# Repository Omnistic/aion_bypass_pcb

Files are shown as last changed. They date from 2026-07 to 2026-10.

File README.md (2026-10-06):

# PCB Design for Hardware Control of Confocal.nl AION in Bypass Mode
## Important Notes ⚠️
- **Current progress**: the board has been designed, printed, assembled, and tested on its own. The controller has also been tested on our microscope successfully. Using the `SELECT` line, one can either use the AION (Confocal.nl) or a FRAP/TIRF module with the AION in bypass mode.
- Floating (digital) inputs should be avoided in a channel that is actively used. I had the case when testing the board, if I only wired one input, the other floating (not wired) input could be `HIGH`.
- When testing the board, the capacitor value changes depending on how many have been soldered to the board already. If a single capacitor is soldered to the board, a multi-meter should still read 100nF. When two capacitors are soldered to the board, and one measures the value of one capacitor, it indicates 200nF. That is because the capacitors are effectively in parallel and their value adds up. With all four capacitors soldered to the board, they should all read 400nF.
## Problem
The AION microscope is controlled by Confocal.nl's own controller. The Confocal.nl controller can also be controlled by the Inscoper Device Controller. The Inscoper Device Controller can control other devices as well. For this reason, the AION can be set into an _optical bypass mode_, which allows accessing the cameras through the AION without making use of the ReScan, to instead perform other kinds of microscopy. However, the cameras and the laser lines (analog and digital) are normally wired to the Confocal.nl controller. This limits the way in which the cameras and the laser lines can be controlled at the level of the Inscoper Device Controller for use in other applications.
## Solution
For two controllers to send signals to the same device, multiplexing is necessary. In the case of the camera trigger (digital) signal, it is not possible to simply use a T-connector because if one controller is high and the other is low a large short-circuit current would flow directly between the two controllers' outputs as they fight each other, potentially damaging the controllers, while the shared node would sit at an undefined voltage that the device could not reliably interpret as high or low.
## Requirements
**⚠️ Those are for my particular case, please check the documentation of your devices accordingly.**
### Devices To Multiplex
#### Oxxius L6Cc With 4 Laser Lines
- 4 digital lines
- 4 analog lines
- Voltage Range (analog and digital): 0-5V
- Input Impedance (analog and digital): 500Ω
#### 2x Kinetix (10Mpix Version)
- 2 digital lines (Trigger In) / 1 per camera
- Voltage Range: 0-5V
- Input Impedance: Unknown
  - For reference, a similar ORCA-Fusion BT has an impedance of 10kΩ
### Selected ICs
#### Digital Multiplexing
`SN74HC157N` is a 4 x 2:1 digital multiplexer, with a single `SELECT` bit. Two will be used for a total of 8 (2:1) digital channels. Although only 6 are required.
#### Analog Multiplexing
`CD74HC4053E` is 3 x 2:1 analog multiplexer, with three `SELECT` bits (1 per channel). Two will be used for a total of 6 (2:1) analog channels. Although only 4 are required.
### PCB Design Rationale
Assuming up to two lasers are operated simultaneously, the current drawn from 2 digital and 2 analog lines is 40mA. On top of that, the two cameras only contribute 1mA (assuming 10kΩ). Multiplying by a safety factor of 1.2 that is about 50mA. The power will be supplied to the board via the Inscoper Device Controller directly.

All the `SELECT` bits are common and a single `SELECT` signal is also taken from the Inscoper Device Controller. This signal effectively switches between AION control and Inscoper control (for the cameras and lasers).

The `SELECT` line is pulled down by a 10kΩ resistor, defaulting to LOW, which corresponds to AION (for my use case).

Only the `SELECT` crosses the PCB with minimal length in the back face to keep continuous ground zone.

100nF capacitors are used on each IC for decoupling.

Vertical through-hole SMA connectors will be soldered to the PCB. The PCB will be mounted in a case and a front panel will have SMA (inside facing) to SMB (outside facing) connectors. Minimum distance between SMA connectors optimized for accessible mounting.

## Overview
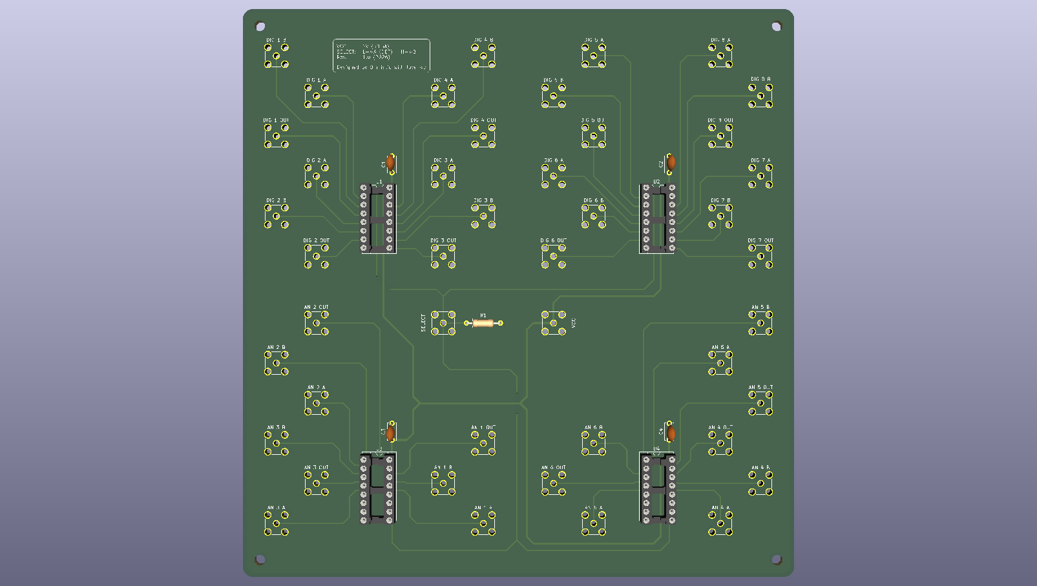
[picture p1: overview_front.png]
PCB Front View

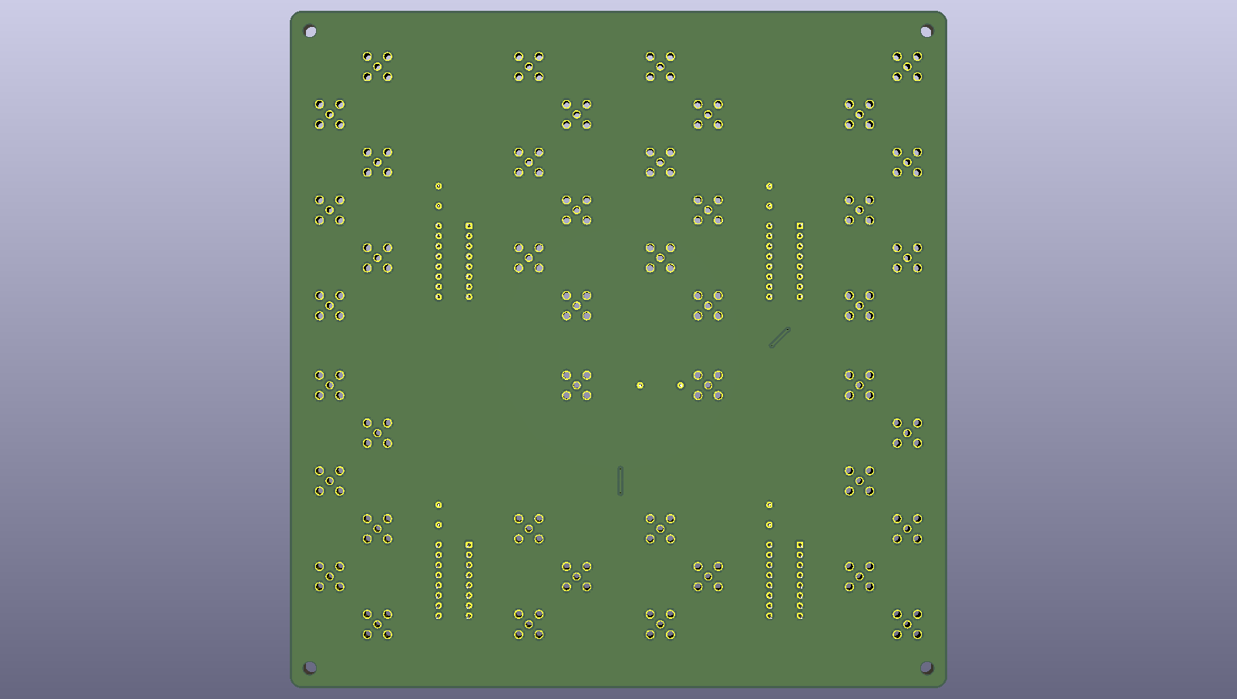
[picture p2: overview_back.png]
PCB Back View


## Realization
- Printed by JLCPCB for about 32USD (5xPCBs = 18USD + shipping = 14USD)
- Soldered manually
- We have a local electronics workshop and I'm not sure if the price are truly accurate to the market but here is a small cost breakdown:
  - **32x SMA connectors = 256USD**
  - 4x 16-pin sockets = 1USD
  - 2x SN74HC157N = 2.2USD (bought from DigiKey)
  - 2x CD74HC4053E = 1.3USD (bought from DigiKey)
  - 4x 100nF = 0.25USD
  - 1x 10kΩ = 0.05USD

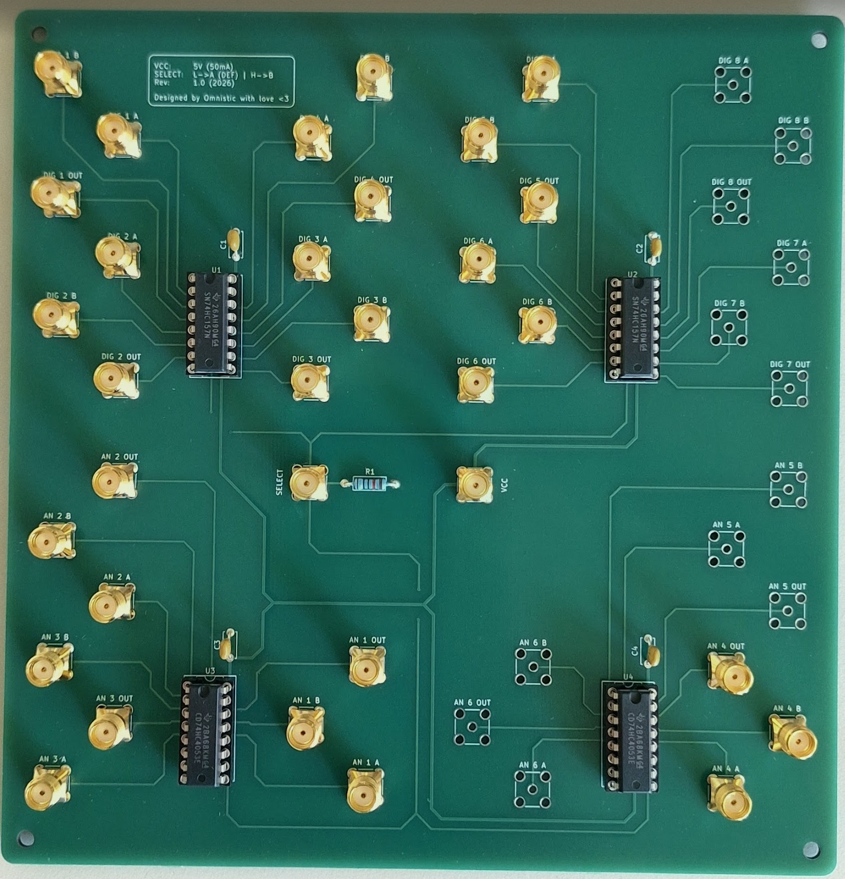
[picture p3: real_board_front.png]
PCB Real Front View


## Enclosure
- 1x Enclosure [1401E (Hammond)](https://www.hammfg.com/electronics/small-case/general-purpose/1401) = 110USD
- 32x SMA-Bulkhead cable [794-2885 (RS PRO)](https://uk.rs-online.com/web/p/coaxial-cable/7942885?gb=a) = 640USD

Note: I originally ordered SMA-Bulkhead cables that were thicker (not intentionally) but they sent only a few and the others were on back order. I cancelled the order and got those above that are thinner. The reason I say this is because it is easier to assemble with the thin cables imo. And also, I am sorry for the poor cable management... The enclosure foot print is perhaps a tiny bit too small but it works.

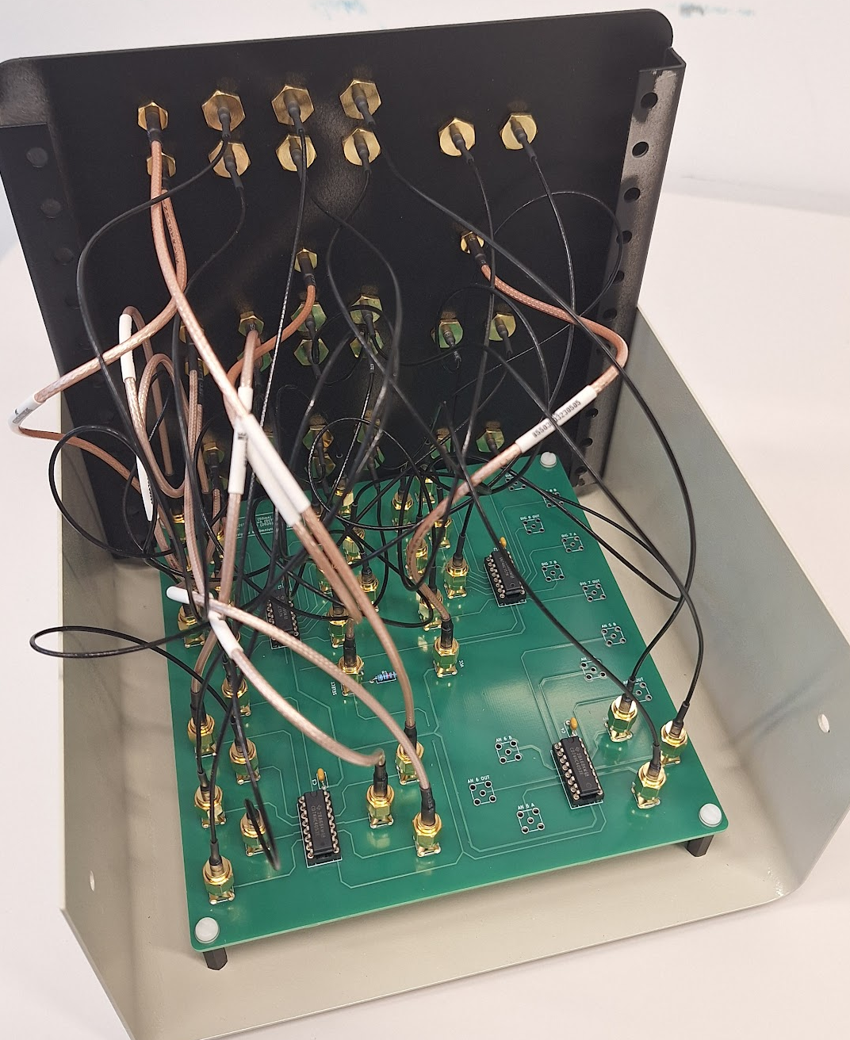
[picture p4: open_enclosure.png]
Open Enclosure

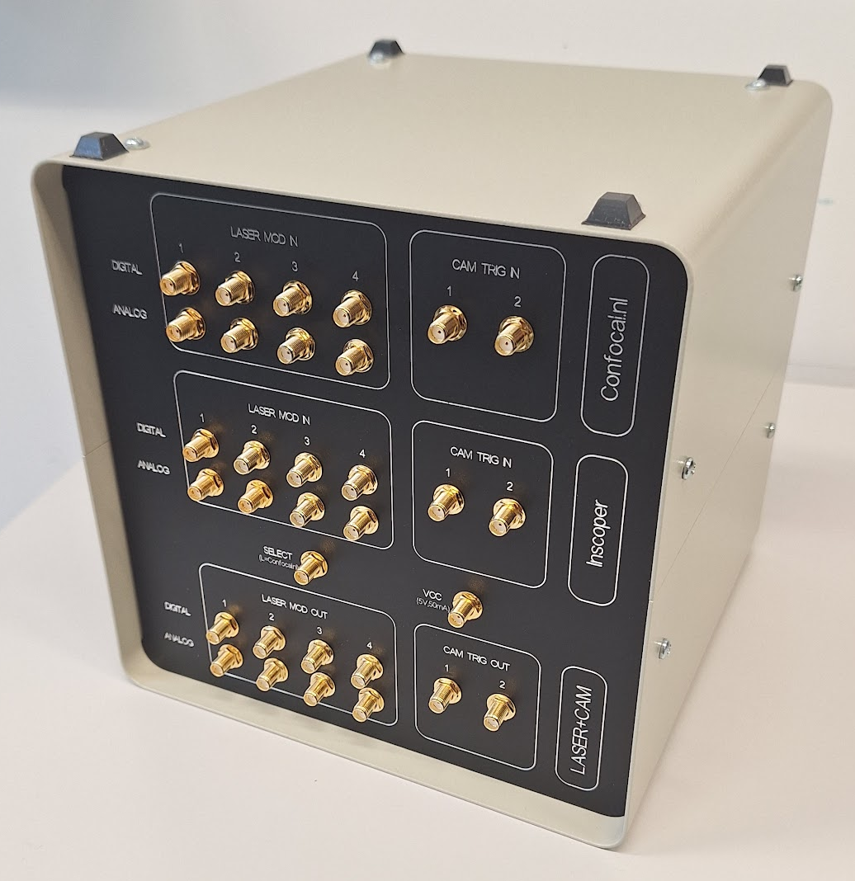
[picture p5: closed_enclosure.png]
Closed Enclosure


## Acknowledgements
We thank Alfonso Fontao Blanco from the [Microelectronics Design Center (ETHZ)](https://dz.ethz.ch/) for kindly reviewing the design and suggesting minor improvements (more distance between SMA connectors, mounting holes, shorter `SELECT` line on the back face).

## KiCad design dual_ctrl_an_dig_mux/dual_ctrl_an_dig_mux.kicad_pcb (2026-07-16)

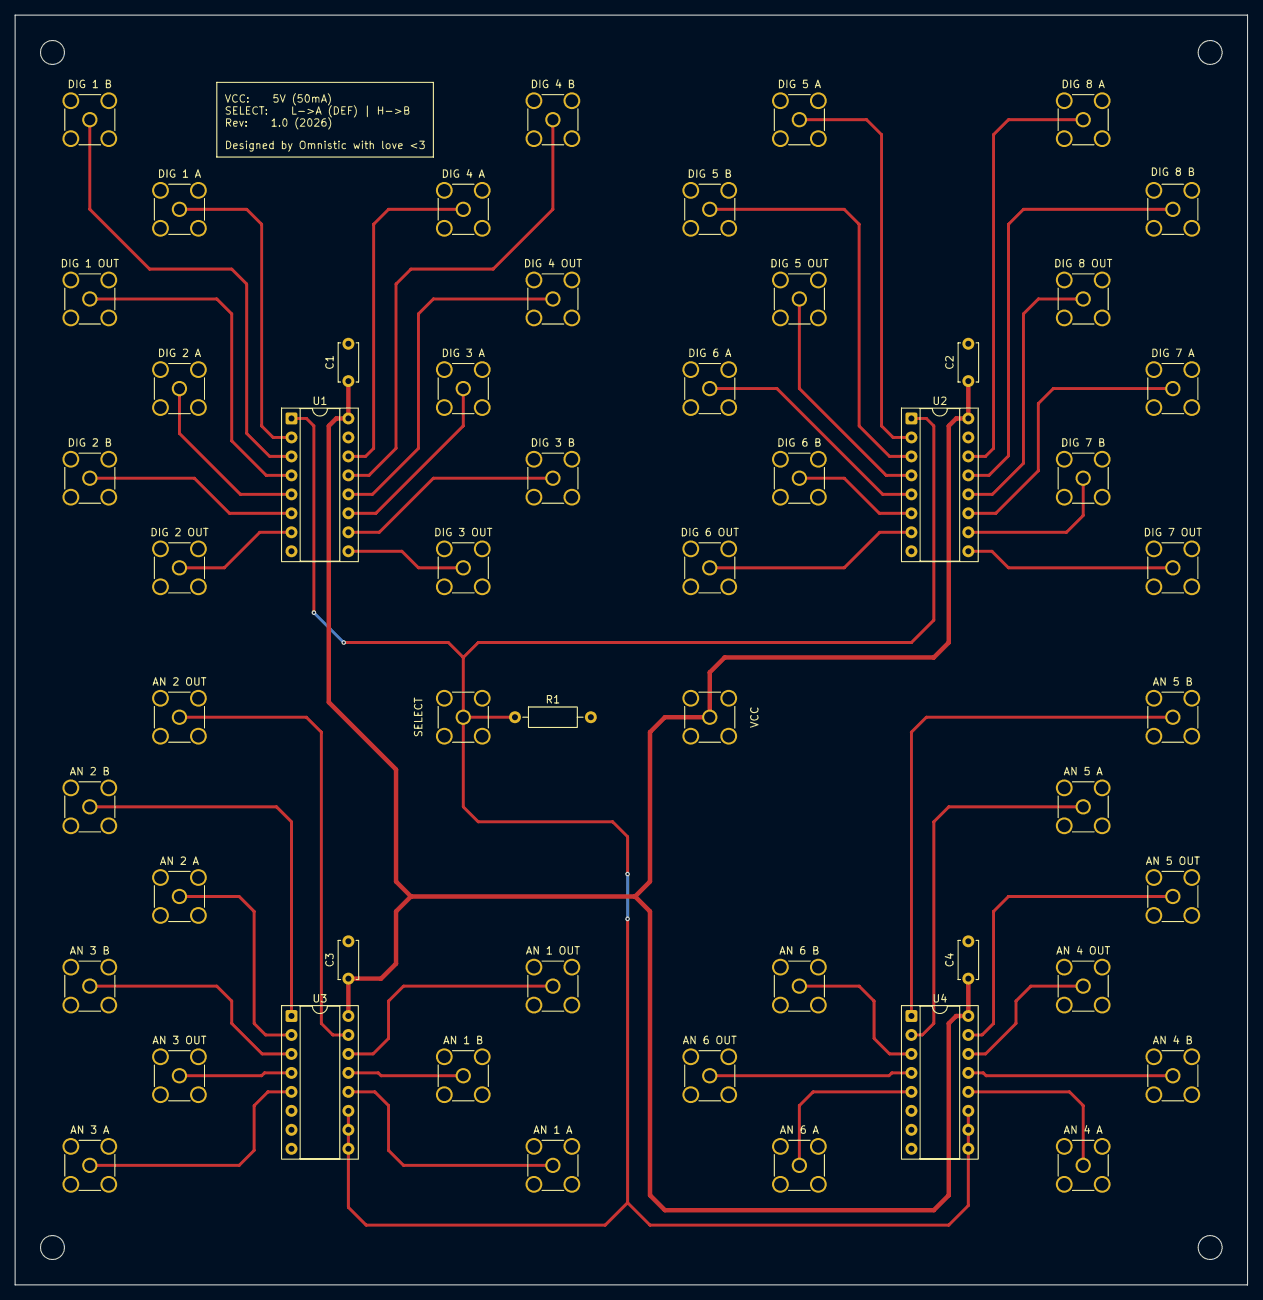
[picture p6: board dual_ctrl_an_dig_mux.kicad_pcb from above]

Board: 2 copper layers, 165.0 x 170.0 mm, 53 parts (0 on the bottom side), 45 nets.

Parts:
AN 1 A, AN 1 B, AN 1 OUT, AN 2 A, AN 2 B, AN 2 OUT, AN 3 A, AN 3 B, AN 3 OUT, AN 4 A, AN 4 B, AN 4 OUT, AN 5 A, AN 5 B, AN 5 OUT, AN 6 A, AN 6 B, AN 6 OUT: Conn_Coaxial; SMA_Amphenol_901-144_Vertical
C1, C2, C3, C4: 100nF; C_Disc_D5.0mm_W2.5mm_P5.00mm
DIG 1 A, DIG 1 B, DIG 1 OUT, DIG 2 A, DIG 2 B, DIG 2 OUT, DIG 3 A, DIG 3 B, DIG 3 OUT, DIG 4 A, DIG 4 B, DIG 4 OUT, DIG 5 A, DIG 5 B, DIG 5 OUT, DIG 6 A, DIG 6 B, DIG 6 OUT, DIG 7 A, DIG 7 B, DIG 7 OUT, DIG 8 A, DIG 8 B, DIG 8 OUT: Conn_Coaxial; SMA_Amphenol_901-144_Vertical
R1: 10k; R_Axial_DIN0207_L6.3mm_D2.5mm_P10.16mm_Horizontal
SELECT: Conn_Coaxial; SMA_Amphenol_901-144_Vertical
U1, U2: 74HC157; DIP-16_W7.62mm_Socket
U3, U4: 74HC4053; DIP-16_W7.62mm_Socket
VCC: Conn_Coaxial; SMA_Amphenol_901-144_Vertical

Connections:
GND: AN 1 A.2 (Ext), AN 1 B.2 (Ext), AN 1 OUT.2 (Ext), AN 2 A.2 (Ext), AN 2 B.2 (Ext), AN 2 OUT.2 (Ext), AN 3 A.2 (Ext), AN 3 B.2 (Ext), AN 3 OUT.2 (Ext), AN 4 A.2 (Ext), AN 4 B.2 (Ext), AN 4 OUT.2 (Ext), AN 5 A.2 (Ext), AN 5 B.2 (Ext), AN 5 OUT.2 (Ext), AN 6 A.2 (Ext), AN 6 B.2 (Ext), AN 6 OUT.2 (Ext), C1.2, C2.2, C3.2, C4.2, DIG 1 A.2 (Ext), DIG 1 B.2 (Ext), DIG 1 OUT.2 (Ext), DIG 2 A.2 (Ext), DIG 2 B.2 (Ext), DIG 2 OUT.2 (Ext), DIG 3 A.2 (Ext), DIG 3 B.2 (Ext), DIG 3 OUT.2 (Ext), DIG 4 A.2 (Ext), DIG 4 B.2 (Ext), DIG 4 OUT.2 (Ext), DIG 5 A.2 (Ext), DIG 5 B.2 (Ext), DIG 5 OUT.2 (Ext), DIG 6 A.2 (Ext), DIG 6 B.2 (Ext), DIG 6 OUT.2 (Ext), DIG 7 A.2 (Ext), DIG 7 B.2 (Ext), DIG 7 OUT.2 (Ext), DIG 8 A.2 (Ext), DIG 8 B.2 (Ext), DIG 8 OUT.2 (Ext), R1.2, SELECT.2 (Ext), U1.8 (GND), U1.15 (E), U2.8 (GND), U2.15 (E), U3.6 (INH), U3.7 (VEE), U3.8 (VSS), U4.6 (INH), U4.7 (VEE), U4.8 (VSS), VCC.2 (Ext)
unnamed: R1.1, SELECT.1 (In), U1.1 (S), U2.1 (S), U3.9 (S3), U3.10 (S2), U3.11 (S1), U4.9 (S3), U4.10 (S2), U4.11 (S1)
unnamed: DIG 2 B.1 (In), U1.6 (I1b)
unnamed: DIG 2 A.1 (In), U1.5 (I0b)
unnamed: DIG 1 B.1 (In), U1.3 (I1a)
unnamed: DIG 1 A.1 (In), U1.2 (I0a)
unnamed: DIG 3 A.1 (In), U1.11 (I0c)
unnamed: DIG 3 B.1 (In), U1.10 (I1c)
unnamed: DIG 4 A.1 (In), U1.14 (I0d)
unnamed: DIG 4 B.1 (In), U1.13 (I1d)
unnamed: DIG 4 OUT.1 (In), U1.12 (Zd)
unnamed: DIG 3 OUT.1 (In), U1.9 (Zc)
unnamed: DIG 2 OUT.1 (In), U1.7 (Zb)
unnamed: DIG 1 OUT.1 (In), U1.4 (Za)
unnamed: DIG 5 A.1 (In), U2.2 (I0a)
unnamed: DIG 5 B.1 (In), U2.3 (I1a)
unnamed: DIG 6 A.1 (In), U2.5 (I0b)
unnamed: DIG 6 B.1 (In), U2.6 (I1b)
unnamed: DIG 7 A.1 (In), U2.11 (I0c)
unnamed: DIG 7 B.1 (In), U2.10 (I1c)
unnamed: DIG 8 A.1 (In), U2.14 (I0d)
unnamed: DIG 8 B.1 (In), U2.13 (I1d)
unnamed: DIG 5 OUT.1 (In), U2.4 (Za)
unnamed: DIG 6 OUT.1 (In), U2.7 (Zb)
unnamed: DIG 7 OUT.1 (In), U2.9 (Zc)
unnamed: DIG 8 OUT.1 (In), U2.12 (Zd)
unnamed: AN 3 OUT.1 (In), U3.4 (C)
unnamed: AN 2 OUT.1 (In), U3.15 (B)
unnamed: AN 1 OUT.1 (In), U3.14 (A)
unnamed: AN 4 OUT.1 (In), U4.14 (A)
unnamed: AN 5 OUT.1 (In), U4.15 (B)
unnamed: AN 6 OUT.1 (In), U4.4 (C)
unnamed: AN 3 B.1 (In), U3.3 (C1)
unnamed: AN 3 A.1 (In), U3.5 (C0)
unnamed: AN 2 B.1 (In), U3.1 (B1)
unnamed: AN 2 A.1 (In), U3.2 (B0)
unnamed: AN 1 B.1 (In), U3.13 (A1)
unnamed: AN 1 A.1 (In), U3.12 (A0)
unnamed: AN 4 A.1 (In), U4.12 (A0)
unnamed: AN 4 B.1 (In), U4.13 (A1)
unnamed: AN 5 A.1 (In), U4.2 (B0)
unnamed: AN 5 B.1 (In), U4.1 (B1)
unnamed: AN 6 A.1 (In), U4.5 (C0)
unnamed: AN 6 B.1 (In), U4.3 (C1)
VCC: C1.1, C2.1, C3.1, C4.1, U1.16 (VCC), U2.16 (VCC), U3.16 (VDD), U4.16 (VDD), VCC.1 (In)

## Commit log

2026-07-16 Incorporated feedback from ABF
    [dual_ctrl_an_dig_mux-B_Cu.gbr, dual_ctrl_an_dig_mux-B_Mask.gbr, dual_ctrl_an_dig_mux-B_Paste.gbr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]
2026-07-16 Enhance README with connector details and acknowledgements
    Added acknowledgements and improved PCB connector details.
2026-07-28 Update README with important notes and realization section
    Added important notes regarding board testing and capacitor behavior.
2026-07-28 Revise PCB realization section in README
    Updated PCB realization details including cost and soldering method.
2026-09-11 Update README with enclosure and cable information
    Added enclosure details and cable specifications to the README.
2026-10-02 Revise current progress and controller usage details
    Updated the current progress to include successful testing with the microscope and clarified the use of the SELECT line for module selection.
